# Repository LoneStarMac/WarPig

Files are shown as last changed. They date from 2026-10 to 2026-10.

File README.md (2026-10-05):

# War Pig Beer Bike Float Frame

There have been many war pigs since the mascot was logingly adopted, including a couple iterations of the wooden Beer Bike float. The current woden float has suffered repeated buckling of the 4x4 frame, which is now split beyond repair and prompts us to reimagine the base of the pig again.

A warning lives in the nose of the current wooden pig:
> Hello    
> If you   
> decide to rebuild  
> this pig, do NOT  
> just copy each piece.  
> They are not equal.  
> It is a nightmare.  
> Good luck.  
> ♡ Loryn H. '21  

Sounds like a good idea then.

In this repository you will find structural models of a bolted perforated-square-steel-tube frame for an 8 × 8 × 8 ft octagonal War Pig, replacing the rotting 5-year-old wood frame. Space-frame analysis in [PyNite](https://github.com/JWock82/Pynite), with an interactive 3D viewer, cut list, joint schedule and caster loads.

> These are parametric models built so the team can change dimensions, loads and tube sizes and see the consequences. Before we ride on it, have an engineer review and/or test it well.

**Site:** https://wiess-college.github.io/WarPig/

| Design | What | Page |
|---|---|---|
| [`Beer-Bike-Float/`](Beer-Bike-Float/) | Octagon body with snout and tail, 2½" chassis at deck level, open sides for doors, hatch in the upper deck. PyNite space-frame check with 3D viewer. | ([/WarPig/Beer-Bike-Float/](https://wiess-college.github.io/WarPig/)) | 

## Instructions
To add a design: copy a directory, edit its `model/frame_model.py`, add a row above. The workflow finds every
`*/model/frame_model.py`, runs it, builds that design's page and assembles the site.

One-time setup for the site: Settings → Pages → Build and deployment → Source: **GitHub Actions**.

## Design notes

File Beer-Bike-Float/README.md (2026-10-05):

# War Pig Beer Bike Float Frame

There have been many war pigs since the mascot was logingly adopted, including a couple iterations of the wooden Beer Bike float. The current wooden float has suffered repeated buckling of the 4x4 frame, which is now split beyond repair and prompts us to reimagine the base of the pig again.

A warning lives in the nose of the current wooden pig:
> Hello    
> If you   
> decide to rebuild  
> this pig, do NOT  
> just copy each piece.  
> They are not equal.  
> It is a nightmare.  
> Good luck.  
> ♡ Loryn H. '21  

Sounds like a good idea then.

As near as i can tell, the wood pig was incarnated in 2012 as a trogan horse Beer Bike parade float. Before then there was a flying pig on and off again, and originally there may have briefly been an iron pig.

In this repository you will find a structural model of a bolted perforated-square-steel-tube frame for an 8 × 8 × 8 ft octagonal War Pig, replacing the rotting 5-year-old wood frame. Space-frame analysis in [PyNite](https://github.com/JWock82/Pynite), with an interactive 3D viewer, cut list, joint schedule and caster loads.

**Live page:** https://lonestarmac.github.io/WarPig/Beer-Bike-Float/ 

> This is a parametric model built so the team can change dimensions, loads and tube sizes and see the consequences. Before we ride on it, have an engineer review and/or test it well.

## Current design

| | |
|---|---|
| Body | 96 × 96 × 96 in octagon, 55 in flats, top open. 36 in snout to a 30 × 18 in panel; 20.5 in tail to a 55 × 55 in flap (the door is in it), so every tail face is a 45° cut. |
| Chassis | Two 2.5" × 14 ga rails at ±26" on the octagon's 55" bottom flat, four 2" × 52" cross-members at the ribs (Y = 0, 32, 64, 96), no spine. 16" casters under the rails at 11" from each end, entirely below the body: the feet. |
| Lower deck | 20.5" above the chassis: at each rib a V of 1.5" diagonals from the rail ends up to a 2" deck spine, a 1.5" beam across the apex, and 45° chamfer stubs out to the deck-ring corners. No joists or columns. 0.75" ply spanning 32" between the beams, 40" above the road, i.e. where it is now. |
| Sides | Three 1.75" posts per side at Y = 0, 48, 96: one on each body corner (a nailer for both ply sheets that meet there) and one mid-side. Hard-skinned, two 48 × 55 pieces per side; the panels are the side bracing (fastened along every edge). Optional cable X per side (`CABLES`) as a backstop if the ply ever slips. Entry is through the tail. |
| Upper deck | 1.75" side rails, end beams and two hatch-edge cross beams, 1.5" hatch sides; ply spans 32" between the beams. 48 × 32 in hatch, 97" above the road. |
| Rim | 1.5" handrail stringers 20.5" above the upper deck on 1.5" chamfer stubs at Y = 0, 24, 72, 96 (off the hatch-beam stations, so those rail joints are plain T's), cross pieces at the nose and tail only (nothing to sit on across the opening). Top of frame 113" above the road. |
| Bracing | 1.5" 45° X in the nose wall; four 1.5" long braces from the deck-ring corners of the end ribs up to the hatch-edge beams (front pair to ±12" on the Y=64 beam, rear pair to ±24" on the Y=32 beam); the V's under the deck at every rib; skinned tail-wall panels beside the door; deck, belly, chamfer and side plywood. |
| Underbody | The full octagon: 20.5" lower chamfer to the 55" bottom flat, 17" off the road, with the casters below it. Optional coroplast sleeves with a rubber-seal hoof round each caster, no steel. Rigid casters at the rear, swivels at the front. |
| Steel | ≈ 384 ft, ≈ 532 lb, all 14 ga: 28 ten-ft sticks of 1.5", 12 of 1.75", 3 of 2", 2 of 2.5". (v2 at 12 ga was 1,016 lb.) |
| Weight | ≈ 2,980 lb parked with 6 aboard; ≈ 2,130 lb moving with 2. |
| Casters | 810 lb each parked, 1,490 lb with one wheel in a pothole, 1,420 lb on the downhill side at 0.3 g sideways. Spec 16" wheels ≥ 1,200 lb. Tipping starts at about 0.43 g sideways with 6 aboard; braking lifts the rear wheels at about 0.54 g. A rear-wheel brake is self-limiting: even locked, the rear tires can only hold about 0.22 g, because braking unloads them. So the brake is a spring-applied shoe on each rear tire, pin-released, as strong as you like. |
| Worst member | Chassis rail, 85% of allowable at 0.3 g sideways, now that the caster's 17" lever is in the model (73% with one wheel lifted). The rails were checked at 2": over 100%, so they stay 2.5"; 12 ga rails buy margin for 14 lb. Target is 85%; nothing else over 47% (the hatch-edge beams, braking). Cross-members 34%. |
| Flex | 0.08" sag at the hatch edge with someone sitting on it (the long braces prop it). Front-to-back racking under a rope snatch: 0.09" with every joint a pin. Pothole twist 0.28". |

### Sizing philosophy

The frame is skinned in plywood, and flex is acceptable; what is not acceptable is a yielded tube or a sheared bolt, so members are sized for **strength**: `python model/frame_model.py --optimize` picks, for each member family, the lightest tube from the allowed list that stays under 85% of capacity (yield or buckling) in every load case, and deflection is reported rather than limited. That took the frame from 1,016 lb of 12 ga to 604 lb of 14 ga.
The 14 ga section properties are derived from the 12 ga Telespar datasheet by the gross-section ratio; the actual tube we buy needs to be chcked since some generic perforated tube is 33–36 ksi rather than 50, which would push the chassis back to 12 ga.

Rigidity then comes from the four long braces (34 lb), the deck, belly, chamfer and side plywood screwed to the frame, and the nose and tail pyramids. The body is a closed tube and post brackets no longer matter for stiffness; they are still worth having for consistency of construction.

### Joint philosophy

Two perforated tubes crossing at 90° share exactly one bolt, so every T and corner in this frame is modelled as a pin and the frame is sized so that is enough. Nothing relies on a bolted corner carrying moment. Moment exists only inside continuous sticks (sleeve-spliced with a 12" stub of the next size down) and in the chassis ladder, which we recommend having a shop weld from plain 2.5" tube and paint (about an hour of welding); bolting it with the rails stacked on the cross-members also works, the deck ply holds it square.

Pre-fabicated plates standardise the connections. Verticals lap past their horizontals instead of butting them, so the two tubes share a flat face and a laser-cut flat plate bolts across it, two bolts per leg, no bends. The goal is to design every diagonal in the body at 45°, so there are only two plate patterns: **A, a flat T or L plate** (~90) and **B, a flat 45° plate** (~45: chamfer stubs, X-brace ends, tail stringers). Cone stringers, long braces, lower-box diagonals and V-braces are flattened-end one-bolt pins and need none. Both patterns are a SendCutSend order from 12 ga.

Racking is resisted by the .75" deck plywood acting as shear diaphragms (screw it to the steel every 6–8" along every panel edge; this is the one place fastener spacing matters) and by the nose and tail pyramids, which are rigid in every direction. The 3/8" skin on the two upper chamfer faces is also counted as a light shear panel; without it the rim sways 2" under a tow snatch, so fasten that skin along all its edges or add one hidden diagonal per bay up there.

The busiest joint has five sticks (the four lower corners of the end ribs): cross-member end, edge stringer on top of it, post beside the stringer, skirt stub underneath, cone stringer on the stringer end. Each is a separate one-bolt lap to its neighbour.

Bolts: ⅜" Grade 5 zinc-plated, flange nuts or nylocks, snug-tight only. These are bearing joints; clamp force adds nothing and over-tightening dimples the 0.105" wall. Where a bolt passes through a single tube with nothing inside it, a 1.75" sleeve stub inside the 2" tube lets you tighten harder.

## Building it

The viewer's **Build** tab has the full sequence; the short version:

1. Cut and label every stick; flatten the ends of the cone stringers, long braces, lower-box diagonals and V-braces.
2. Chassis upside down on sawhorses: rails on cross-members, corner plates, caster plates with crush sleeves, belly ply. Flip it onto its wheels.
3. Lower box: at each rib a V from the rail ends to the deck centre, the deck beam across it, chamfer stubs to the corners; then the deck spine and edge stringers. Square and level it.
4. Lower deck ply (two 4 × 8 sheets from above).
5. Posts, side rails, end and hatch-edge beams, hatch sides, nose X-brace, tail-door jambs; then the four long braces, standing on the deck-ring corners of the end ribs and rising to the hatch-edge beams.
6. Upper deck ply from above (a 48" sheet fits the 55" top opening), rim, nose and tail frames, door.
7. Skin bottom up and outside in, every panel fastened along all four edges; paint; decorations; hooves.

**Plates** (`docs/exports/plates/`, DXF for laser cutting, 10 ga zinc-plated steel, slotted so they land on the tube's 1" hole pitch): TP-90 T plate, TL-90 L plate, TP-45 45° plate. Two per joint, one each face; quantities and the bolt schedule (≈620 ⅜"-16 Grade 5 bolts by length, 20 crush sleeves, fender washers) are computed from the model on the Build tab. Torque with threadlocker throughout: 12 ft·lb where there are plates both sides, 8 ft·lb on a bare tube with fender washers, 25 ft·lb at the caster and tow bolts, which have sleeves.
**Plates** (`docs/exports/plates/`, DXF for laser cutting, 10ga zinc-plated steel, slotted so they land on the tube's 1" hole pitch): TP-90 T plate, TL-90 L plate, TP-45 45° plate. Two per joint, one each face; quantities and the bolt schedule (≈620 .375"-16 Grade 5 bolts by length, 20 crush sleeves, fender washers) are computed from the model on the Build tab. Torque with threadlocker throughout: 12 ft·lb where there are plates both sides, 8 ft·lb on a bare tube with fender washers, 25 ft·lb at the caster and tow bolts, which have sleeves.

## Reviewing and changing the design

Everything is driven by the `PARAMETERS` block at the top of [`model/frame_model.py`](model/frame_model.py): dimensions, rib stations, cone sizes, people counts, dynamic factors, tube size per member group, plywood stiffness. Change a value, push to `main`, and the GitHub Action re-runs the model, rebuilds the page and the export files, and redeploys. Open a pull request instead and the Action runs the model and attaches the exports to the run without deploying, so you can review a change before it goes live.

* `docs/index.html` is the page: title, headings, the prose in every tab, the build steps. A number that comes from the model is a `<span data-v="…">` whose attribute is a small expression over the model data (`P` is the parameter block, `S` the per-case summary, `D` everything; `fmt()` formats). A table or figure the script draws is a `<div data-fill="name">`.
* `docs/viewer.css` is the style. `docs/viewer.js` is the script: the 3D scene, the table renderers (the `FILLS` map) and the helpers the `data-v` expressions can use.
* `docs/data.js` is written by `model/build_viewer.py` from the model run. Do not edit it; it is overwritten.
* three.js and its OrbitControls load from jsDelivr, pinned to r128 (the last release with the plain-script build).

To run locally, from this directory:

```bash
pip install -r requirements.txt
python model/frame_model.py            # prints worst members, writes docs/exports/*
python model/make_plates.py            # plate DXFs
python model/build_viewer.py            # writes docs/data.js for the page
```

Open `docs/index.html` in a browser. It loads three.js and fonts from CDNs, so it needs a network connection.

## Files

| Path | What |
|---|---|
| `model/frame_model.py` | The model: geometry, loads, load cases, checks, exports. |
| `model/build_viewer.py` | Turns `results.json` into `docs/data.js`: merged sticks, stock packing, joint census, plate counts, bolt schedule. |
| `model/make_plates.py` | Writes the plate DXFs and their spec to `docs/exports/plates/`. |
| `model/v1/` | Archived absurd first version. Never forget who you are. |
| `docs/index.html`, `viewer.css`, `viewer.js` | The page, its style and its script. |
| `docs/data.js` | Generated model data the page reads. |
| `docs/exports/frame.FCMacro` | FreeCAD macro: Macro → Macros… → Execute. One Part object per member group, inches, plus a compound of all members. |
| `docs/exports/frame.dxf` | Same wireframe as 3D lines, one layer per member group. |
| `docs/exports/cutlist.csv` | Model segments by group, section and length. The viewer's Cut list tab merges them into physical sticks. |
| `notes/` | Design notes for things not yet in the model (the brake). |
| `docs/exports/results.json` | Everything the viewer shows: member forces per load case, displacements, reactions, joint schedule. |

Units: inches and pounds. X across, Y along the length (rear body rib = 0, snout forward), Z up; Z = 0 is the chassis centreline. The road is at Z = −17.25 (16" caster + half a 2.5" tube).
Units: inches and pounds. X across, Y along the length (rear body rib = 0, snout forward), Z up; Z = 0 is the chassis centreline. The road is at Z = −17.25 (16" caster + half a 2.5" tube).

## What the model does and does not do

* 1D beam elements, linear static. Six load cases: parked with 6 aboard; moving with 2 aboard × 2.0 road shock; parked + 0.3 g sideways; moving + rope snatch at the front rail ends; parked with the right-rear wheel off the ground;moving + 0.3 g stop held at the rear wheels only. Casters are stiff legs from the rails to the road, pinned at the tire,so sideways and braking forces overturn about the road and the caster's lever loads the rail and cross-members.
* Member checks: yield (P/A + M/S) and AISC E3 column buckling over the node-to-node length. Shock is checked against nominal strength (it already carries a 2× factor); the other cases against ASD allowables (÷1.67).
* 12ga section properties are the perforated net values from the Unistrut Telespar datasheet; 14ga is scaled from them. F<sub>y</sub> = 50 ksi (ASTM A1011 Gr 50; Unistrut quotes 60 ksi average after forming).
* `--optimize` re-sizes every family from scratch; a plain run uses the sizes baked into `GROUP_SEC`.
* Plywood decks modelled as shear panels at an effective G·t of 15,000 lb/in (APA gives 60–80k for .75" sheathing before fastener slip). This is the assumption most worth an engineer's eye.
* `UNDERBODY` ('octagon', 'chamfer', 'legs' or 'skirt'), `ENTRY` ('tail' or 'side'), `LONG_BRACES`, `SIDE_BRACING` ('skin', 'diagonals', 'none'), `POST_Y`, `CHAMFER_Y`, `UPPER_JOISTS`, `RIM_CROSS`, `LOWER_WEB` ('vee': V to a deck spine at every rib; 'vee_ends': V's at the end ribs only, needs a 2.5" spine; 'pratt': side trusses with columns and diagonals), `CABLES` (tension-only cable X's: 'sides', 'nose'; `CABLE_D` picks ⅛", 3/16" or 1 4" 7×19 cable, checked at breaking/5) and `SPINE` switch between the v8 to v3 layouts. 'octagon' puts the chassis on the bottom flat with the casters below it; the other three keep the chassis at the lower deck with the casters inside the body, which rides 20" lower.
* Not modelled: local wall dimpling under a bolt, hole slop, skin on the sides, belly, legs and cones, wind.

## To do

* **Brake.** Not designed in. A rear-wheel-only tread-shoe brake, over-centre handbrake lever with a gas-strut assist and a ratchet, drop chocks as the no-operator backstop; the physics (rear lifts at ~0.54 g, a locked rear tire can only give ~0.22 g, so the brake cannot be too strong) and the mechanism are written up in [`notes/brake.md`](notes/brake.md) for when the design moves forward.
* **Brake.** Not designed in. A rear-wheel-only tread-shoe brake, over-centre handbrake lever with a gas-strut assist and a ratchet, drop chocks as the no-operator backstop; the physics (rear lifts at ~0.54 g, a locked rear tire can only give ~0.22 g, so the brake cannot be too strong) and the mechanism are written up in [`notes/brake.md`](notes/brake.md) for when the design moves forward.

## Sources

* [Telespar datasheet: section properties, material](https://unistrut.biz/content/Resources/General/Telespar-DataSheet.pdf)
* [Telespar 2 × 2 × 12ga 10 ft post, street price](https://squarefittings.com/store/telspar-2-x-2-square-sign-post-with-holes-10-tall-12-gauge-pre-galv-plus-g90.html)
* [PyNite](https://github.com/JWock82/Pynite), [ezdxf](https://github.com/mozman/ezdxf), [three.js](https://threejs.org/)

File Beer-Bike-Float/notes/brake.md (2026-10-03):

# Brake: notes for later

Status: **to do, not designed in.** Nothing in the frame model depends on this. The numbers below come from the
model's Stop case (`STOP_G`, rear tyres braked, crowd moving) and some hand arithmetic; revisit them if the
casters, the CG or the crowd change.

## What the physics says

* The body is tall and the crowd sits high, so a stop is a pitch problem before it is a strength problem. The
  frame is at 47% in the Stop case; the rear wheels are the limit. At 0.3 g braking the rear pair keeps 455 of its
  1,015 lb, so the rear lifts at about **0.54 g**. Sideways tipping starts at about 0.43 g with 6 aboard.
* **Any brake goes on the rear wheels only**, and then it cannot overdo it: every bit of braking unloads the rear
  tyres, and they can only hold μ × load. Even a locked rear wheel on dry asphalt (μ 0.8) manages about **0.22 g**,
  a quarter of the way to lifting the rear. So size the brake to lock the wheel and let the tyre do the limiting.
* 3 mph (parade pace) is ~900 ft·lb with 3,000 lb aboard. At 0.22 g that stops in about 1.4 ft; at 0.14 g about
  2.2 ft. Ordinary-car braking, nothing dramatic for people sitting down.
* A dragging panel does nothing: friction is μ × load and a dropped sheet only drags its own weight. A skid only
  brakes if it lifts a wheel, which is a chock with extra steps.

## Layout

* **Rigid casters at the rear, swivels at the front.** Then the rear tyre path is fixed, the shoes know where the
  tyre is, and the float tracks straight when pushed from behind.
* **One shoe per rear tyre on a hinged arm.** There is no room above the tyre (the 16" wheel top meets the rail
  underside), so the arm hangs from a bracket on the chassis rail behind the tyre, shoe at axle height, pressed
  forward into the tread. Pivot an inch or two aft of straight-above-the-shoe so the tyre's rotation drags the shoe
  in harder (leading-shoe effect, ×2–3). Since the tyre caps the stop, a self-energizing shoe that locks is fine.
  Shoe face: a slab of conveyor belt or truck mudflap on a steel backer, rubber on rubber μ ≈ 0.6 dry, ~0.4 wet.
* **Not drawer slides.** The braking friction is a side load across a slide, which is the loading ball slides are
  worst at, and they pack with grit. One bolt pivot does the job.
* **Equalizer.** One cable from the lever to a balance bar (handbrake "compensator"), two cables to the arms.
  Without it the strong shoe locks and the weak one idles, and the pig yaws as it stops. Barrel adjusters or a
  turnbuckle in each cable: shoes and tyres wear.

## Lever: over-centre handbrake with gas-strut assist

The preferred version. Pull back = brake, push forward flat = released. It is a car handbrake with an
over-centre strut, so the instinctive panic motion (yank back) is the right one.

* A gas strut on the lever whose line of action crosses the pivot ~20° into the pull. Forward of centre it holds
  the lever released; past centre it pulls the lever on. Its torque is force × offset from the pivot, zero at
  centre and growing with angle, so the brake comes on over the second half of the travel: that is the slow stop.
* Put dead centre early so any deliberate pull passes it; a lever stalled at dead centre is in neutral equilibrium.
  Keep the released hold-off weak, 10–15 lb at the handle, so a trip cord can pull it through (below) but bumps
  and vibration cannot.
* **Ratchet sector and pawl, not a single parking pin.** Holds any position (half-applied on a slope during a
  halt), and parks without relying on the strut, which loses force in the cold and over the years. Golf-cart and
  UTV hand-brake lever assemblies have the ratchet, the release button and the cable fitting built in, $30–60;
  buy that rather than make it.
* Release: pull back a notch to unload the pawl, press the button, push forward over centre until flat. A stop
  defines "flat" with the shoes a finger's width off the tyres.
* Numbers that land where we want: 100 lb strut at 4" from the pivot = 400 in·lb; cable off the lever at 2",
  handle at 20" (10:1 for the operator) → 200 lb of cable, 100 lb per shoe, ×2.5 leading-shoe → ~250 lb on each
  tread → about 0.14 g, two-thirds of what the tyres will give. The operator's extra 50 lb at the handle adds
  500 lb of cable and locks the wheels; the tyre caps it there.
* **Caveat: this fails released.** If nobody is at the handle nothing happens. Keep a no-operator layer: a trip
  cord from the handle along the lower deck so any rider can yank it through centre, and/or the drop chocks.

## Alternative: spring-applied shoe, pin-released (fails braked)

* Same arms and shoes, but a spring (two 100 lb gas struts per shoe, or a garage-door extension spring on a 2:1
  lever) pulls the shoe on. The arm is held off by a short cable to a **pelican hook** (sailing hardware, releases
  a loaded line with a small tug on its ring); lanyard on the ring to the rider, light zip tie through the ring as
  the vibration keeper. Fails braked if the lanyard, hook or cable goes; fails unbraked only if the spring breaks.
* Do not hold a 300 lb spring with a plain pin: a pin loaded in shear binds, and pulling it takes a 50–60 lb yank
  at the moment it must not stick.
* Re-cocking compresses a 200–300 lb spring: build in a 4:1 lever on the arm or use a small ratchet strap to the
  rail, so nobody does it with fingers next to the tyre.

## Stage two: drop chocks

* Rubber wheel chocks (5–6" high, ~35° face) hung by a strap from the rail just ahead of each rear tyre, held in
  a cradle by a pin on a rope to the rider. Pull the pin, the chock lands on its tether in the wheel path within
  one revolution; the tether keeps it aligned.
* A positive stop at walking pace: a 5" chock absorbs ~600 ft·lb lifting the rear, which at 2 mph stops the float
  in the length of the ramp at ~0.25 g. At 3 mph it is marginal (900 ft·lb to absorb, and the pitch unloads the rear
  wheels exactly as they climb), so it may hop the chock. A backstop for the shoes, not the brake.
* Chocks ahead of the rear wheels only stop forward motion. Houston is flat; one direction is probably enough.

## Guarding and loads into the frame

* The shoe arm snaps into a 16" tyre at parade speed; the tyre does not care, a hand does. Sheet-metal cover over
  the arm; the hoof skin can do double duty.
* Shoe normal force (~250–700 lb) goes into the rail bracket and the caster fork as a horizontal push at axle
  height; a 16" caster rated 1,200 lb shrugs that off (a kerb is worse). The braking force reaches the chassis
  through the caster plate: at 0.22 g that is ~230 lb per wheel × 17" of caster = 3,900 in·lb on the 4" plate,
  ~1,000 lb on the outer bolt pair, well inside a ⅜" Grade 5 with the crush sleeves.

## Open questions

* Shoe μ wet; try it on the actual tyres before trusting the 0.14 g figure.
* Strut sizing against the real lever and cable losses: expect to change the strut once.
* Whether the rear casters' forks have anywhere to mount the arm brackets, or everything hangs from the rail.
* If the design goes ahead, add the brackets and the cable run to the model and the cut list, and the arms to the
  hardware schedule.

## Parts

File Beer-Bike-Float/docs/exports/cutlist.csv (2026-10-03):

group | section | length_in | qty | total_ft | total_lb
chamfer_hi | 1.50x14 | 29.0 | 8 | 19.3 | 24.0
chassis_cross | 2.00x14 | 26.0 | 8 | 17.3 | 30.4
chassis_rail | 2.50x14 | 11.0 | 2 | 1.8 | 4.2
chassis_rail | 2.50x14 | 13.0 | 2 | 2.2 | 4.9
chassis_rail | 2.50x14 | 16.0 | 4 | 5.3 | 12.1
chassis_rail | 2.50x14 | 19.0 | 2 | 3.2 | 7.2
chassis_rail | 2.50x14 | 21.0 | 2 | 3.5 | 8.0
deck_hi_cross | 1.75x14 | 2.0 | 2 | 0.3 | 0.5
deck_hi_cross | 1.75x14 | 12.0 | 2 | 2.0 | 3.0
deck_hi_cross | 1.75x14 | 14.0 | 2 | 2.3 | 3.5
deck_hi_cross | 1.75x14 | 22.0 | 4 | 7.3 | 11.0
deck_hi_cross | 1.75x14 | 24.0 | 2 | 4.0 | 6.0
deck_hi_end | 1.75x14 | 7.0 | 2 | 1.2 | 1.7
deck_hi_end | 1.75x14 | 11.0 | 2 | 1.8 | 2.7
deck_hi_end | 1.75x14 | 15.0 | 2 | 2.5 | 3.7
deck_hi_end | 1.75x14 | 19.0 | 2 | 3.2 | 4.7
deck_hi_end | 1.75x14 | 22.0 | 4 | 7.3 | 11.0
deck_hi_rail | 1.75x14 | 8.0 | 4 | 2.7 | 4.0
deck_hi_rail | 1.75x14 | 16.0 | 4 | 5.3 | 8.0
deck_hi_rail | 1.75x14 | 24.0 | 4 | 8.0 | 12.0
deck_lo_beam | 1.50x14 | 15.0 | 2 | 2.5 | 3.1
deck_lo_beam | 1.50x14 | 33.0 | 2 | 5.5 | 6.8
deck_lo_beam | 1.50x14 | 48.0 | 6 | 24.0 | 29.8
deck_lo_edge | 1.75x14 | 8.0 | 4 | 2.7 | 4.0
deck_lo_edge | 1.75x14 | 16.0 | 4 | 5.3 | 8.0
deck_lo_edge | 1.75x14 | 24.0 | 4 | 8.0 | 12.0
deck_spine | 2.00x14 | 16.0 | 2 | 2.7 | 4.7
deck_spine | 2.00x14 | 32.0 | 2 | 5.3 | 9.3
door_jamb | 1.75x14 | 55.0 | 2 | 9.2 | 13.7
joist_hi | 1.50x14 | 32.0 | 2 | 5.3 | 6.6
long_brace | 1.50x14 | 68.0 | 2 | 11.3 | 14.1
long_brace | 1.50x14 | 73.1 | 2 | 12.2 | 15.1
nose_rim | 1.50x14 | 18.0 | 2 | 3.0 | 3.7
nose_rim | 1.50x14 | 30.0 | 2 | 5.0 | 6.2
nose_stringer | 1.50x14 | 52.2 | 4 | 17.4 | 21.6
nose_stringer | 1.50x14 | 54.2 | 2 | 9.0 | 11.2
nose_stringer | 1.50x14 | 54.5 | 2 | 9.1 | 11.3
post | 1.75x14 | 55.0 | 6 | 27.5 | 41.2
rim_cross | 1.50x14 | 55.0 | 2 | 9.2 | 11.4
rim_stringer | 1.50x14 | 24.0 | 4 | 8.0 | 9.9
rim_stringer | 1.50x14 | 48.0 | 2 | 8.0 | 9.9
skirt_stub | 1.50x14 | 30.1 | 8 | 20.1 | 24.9
tail_rim | 1.50x14 | 55.0 | 4 | 18.3 | 22.8
tail_stringer | 1.50x14 | 29.0 | 8 | 19.3 | 24.0
vbrace_lo | 1.50x14 | 33.1 | 8 | 22.1 | 27.4
xbrace_end | 1.50x14 | 9.9 | 2 | 1.7 | 2.0
xbrace_end | 1.50x14 | 67.9 | 2 | 11.3 | 14.1
TOTAL |  |  | 156 | 383.6 | 531.7

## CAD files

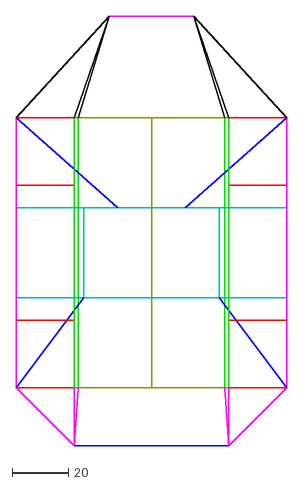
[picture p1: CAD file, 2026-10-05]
Beer-Bike-Float/docs/exports/frame.dxf
96.0 x 152.5

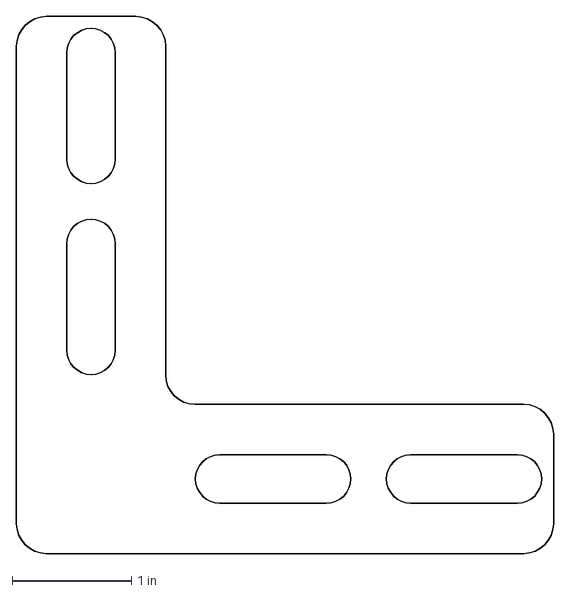
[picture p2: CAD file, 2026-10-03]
Beer-Bike-Float/docs/exports/plates/TL-90.dxf
4.50 x 4.50 in

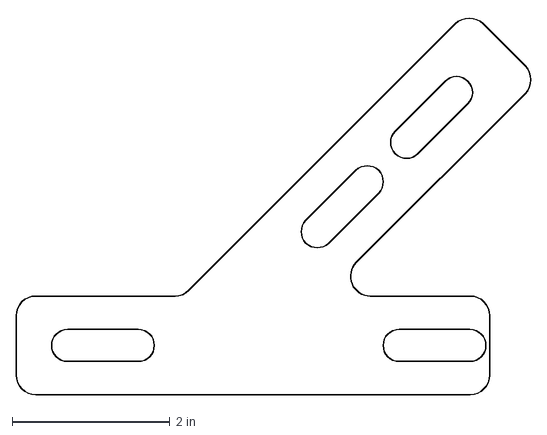
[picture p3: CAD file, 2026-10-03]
Beer-Bike-Float/docs/exports/plates/TP-45.dxf
6.52 x 4.79 in

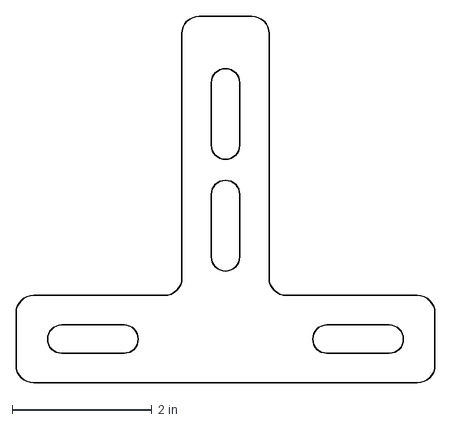
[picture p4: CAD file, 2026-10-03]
Beer-Bike-Float/docs/exports/plates/TP-90.dxf
6.00 x 5.25 in

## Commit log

2026-10-03 Initial load for float
    [cutlist.csv, frame.dxf]
2026-10-03 Beer-Bike-Float v3: strength-only sizing, 14 ga, 45-degree braces, bracket census; Pages workflow
    Auto-sizer picks the lightest tube per member family under 85% capacity in every case:
    604 lb of 14 ga instead of 1,016 lb of 12 ga. X-braces now 45 deg so the body needs two
    bracket patterns; the Joints tab counts them. Post brackets cut rope-snatch racking from
    2.1 in to 0.24 in. Adds the GitHub Actions workflow (dotfiles were dropped in the first upload).
    Claude-Session: https://claude.ai/code/session_01JGCbkCmeCncUNmH1Jovgc3
    [cutlist.csv, frame.dxf]
2026-10-03 Beer-Bike-Float v4: legs instead of skirt, tail door, braced hard-skinned sides
    Each caster in its own leg box 4 in off the road, belly flat at the chassis (16 in clear).
    Entry through the tail (30 x 55 door, flat-floored tail tunnel); side walls get one diagonal
    per bay and hard skin. Rope-snatch racking drops from 2.1 in to 0.05 in with every joint pinned.
    636 lb of steel. UNDERBODY/ENTRY parameters keep the v3 layout available.
    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
    [cutlist.csv, frame.dxf]
2026-10-03 Beer-Bike-Float v5: tapered belly back, coroplast legs with rubber hooves
    Lower chamfer returns as skin framing down to an 81.5 in belly 10 in off the road (BELLY_CLEAR).
    Legs are round coroplast with garage-door-seal hooves, no steel. 617 lb of steel.
    UNDERBODY now: chamfer / legs / skirt.
    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
    [cutlist.csv, frame.dxf]
2026-10-03 Beer-Bike-Float v6: full octagon on its feet
    UNDERBODY='octagon': 2.5 in chassis on the 55 in bottom flat, 16 in casters entirely below
    the body, 1.5 in lower deck frame on 20.5 in columns with 45 deg chamfer stubs, V-braces
    below the deck in the end walls, lower chamfer skin and belly ply as shear panels.
    Deck 40 in and rim 113 in above the road, matching the existing float. 655 lb of steel.
    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
    [cutlist.csv, frame.dxf]
2026-10-03 Beer-Bike-Float v7: long braces to the hatch-edge beams, side panels as the side bracing
    Four 1.5 in long braces from the chassis ends up to the hatch-edge beams (V at the front landing
    at +/-12, pair at the rear from +/-18 to +/-24), routed clear of the lower deck joists. Hatch-edge sag
    0.48 -> 0.08 in, pothole twist 0.55 -> 0.30 in, upper deck frame drops to 1.75 in. Side-wall
    diagonals removed; the hard side panels are counted as shear panels (SIDE_BRACING). 638 lb.
    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
    [cutlist.csv, frame.dxf]
2026-10-03 Revise README for War Pig float project
    Updated description of the octagonal float frame and removed setup instructions.
2026-10-03 Beer-Bike-Float v8: trussed lower box, staggered posts, fewer joists, 45-degree tail
    Lower box: rail + joist + columns + one diagonal per bay each side; spine, centre joist and centre
    columns dropped. Rails checked at 2 in (121% 14 ga, 92% 12 ga in the pothole case) so they stay
    2.5 in; cross-members to 2 in. Three posts per side at Y=16/48/80 lapping continuous rails for flat
    T plates. Rim crosses at the ends only; upper joists reduced to the hatch sides. Tail 55x55 at 20.5 in
    so every tail face is a 45 deg cut. 569 lb of steel.
    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
    [cutlist.csv, frame.dxf]
2026-10-03 Beer-Bike-Float: build package - plate DXFs, bolt and torque schedule, build order, painted-pig layer
    make_plates.py writes TP-90 / TL-90 / TP-45 slotted flat plates (10 ga) as DXF. The viewer's new
    Build tab gives the assembly order (ply timing included), plate quantities and a bolt schedule by
    length computed from the joint census, crush sleeves, torque values with threadlocker. Joint table
    descriptions now come from the data (the 6- and 7-stick joints are the chassis corners). A
    'Painted pig' checkbox shows the skinned float in deep yellow with face, ears, tail and door.
    Claude-Session: https://claude.ai/code/session_01JGCbkCmeCncU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
    [TL-90.dxf, TP-45.dxf, TP-90.dxf]
2026-10-03 Beer-Bike-Float: long braces re-based onto the truss lines
    Bottoms moved from the cross-member centre / +/-18 to the lower deck beams directly over the
    columns at +/-26, so the load goes brace -> deck beam -> column -> rail. Cross-member utilisation
    58% -> 10%, hatch sag 0.11 -> 0.08 in, no deck-ply slots. 562 lb.
    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
    [cutlist.csv, frame.dxf]
2026-10-03 v8: V-braced lower deck on a 2" spine, chamfer stubs off the hatch stations
    - LOWER_WEB='vee': at every rib a V of 1.5" diagonals from the rail ends up to a
    2" deck spine; deck beams across the apexes. Joists, columns and side diagonals
    removed (22 fewer members). 532 lb, rails 0.73, deck beams 0.33, cross-members
    0.06. 'vee_ends' (V's at the end ribs only, 2.5" spine) kept as an option: 522 lb
    but rails 0.85 and twist 0.38".
    - Long braces and the nose X stand on the deck-ring corners over the chamfer stubs.
    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
    [TL-90.dxf, TP-45.dxf, TP-90.dxf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]
2026-10-03 v8: corner posts, cable option, axial sign fix, 10'/20' stock packing
    - Fix: PyNite reports axial force + in compression; check() had it backwards
    since v1, so compression members skipped the buckling check and tension
    members got it. Long braces 0.05 -> 0.12 (they are props); rails unchanged.
    - POST_Y=[0,48,96]: posts on the body corners (ply nailer for the side and
    end-wall sheets, corners carried directly) and mid-side. Side skin = two
    48x55 pieces per side. Rail 0.75, twist 0.25" (was 0.73 / 0.23").
    - CABLES switch: tension-only 7x19 cable X's ('sides', 'nose') with CABLE_D,
    checked at breaking/5 (2.5 under Shock). Off by default: with the ply
    working they carry 12-22 lb; wit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
    [TL-90.dxf, TP-45.dxf, TP-90.dxf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]
2026-10-03 v8: casters modelled to the road, Stop load case
    - Each caster is a stiff leg from the rail to the road, pinned at the tyre
    contact, so sideways and braking forces overturn about the road and the
    17" lever twists the rail and bends the cross-members. Rail 0.75 -> 0.85
    (Sway now governs), cross-members 0.06 -> 0.34; Lifted unchanged at 0.73.
    - Stop case: moving crowd, 0.3 g forward inertia held at the rear tyres only.
    Frame at 47%; the rear wheels keep 455 of 1,015 lb, so the rear lifts at
    about 0.54 g. Sideways tipping at about 0.43 g with 6 aboard.
    - Viewer: Stop in the case list and caster table, tipping/pitch numbers
    computed from the reactions, braking note; README updated.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
    [frame.dxf]
2026-10-03 Beer-Bike-Float: rear brake is self-limiting (locked rear tyre ≈ 0.22 g); spring-applied shoe note
    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
2026-10-03 Beer-Bike-Float: brake as a to-do with notes/brake.md describing the mechanism
    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
2026-10-03 Fix button states for Color tubes by section
2026-10-03 Beer-Bike-Float: page split into hand-editable index.html + viewer.css + viewer.js + generated data.js
    - docs/index.html is now a static page: prose, build steps and titles are edited
    in place; model numbers are <span data-v="expr"> fills and tables are
    <div data-fill="name"> containers rendered by viewer.js. Keeps the user's
    title "War Pig Steel Frame Design (I am Iron Pig)" and defaults the tube
    colouring to Size.
    - docs/viewer.css and docs/viewer.js hold the style and script that used to be
    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
    [TL-90.dxf, TP-45.dxf, TP-90.dxf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]
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2026-10-05 minor updates to read files
    [frame.dxf]
